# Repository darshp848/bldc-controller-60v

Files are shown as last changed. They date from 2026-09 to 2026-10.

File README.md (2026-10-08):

# bldc-controller-60v

A 48 V nominal / 60 V max BLDC motor controller that fits wherever a MAB Robotics MD80 v3.0
fits: same outline, mounting holes, Micro-Fit and AUX connectors, phase-wire holes and
encoder position, with the MD80's 20 A continuous / 80 A peak phase current.

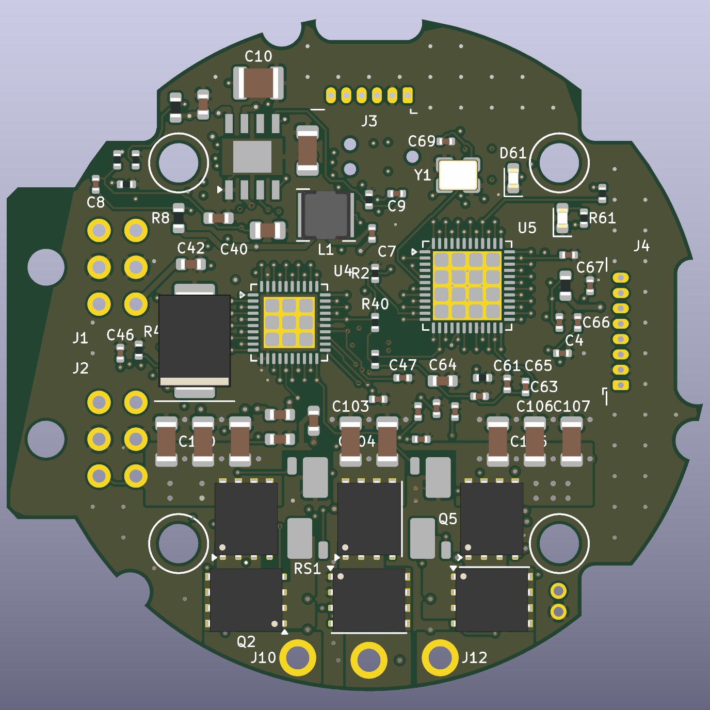
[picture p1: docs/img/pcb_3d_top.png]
top


## Status

| Item | State |
|---|---|
| Schematic (KiCad 10, 6 sheets, 137 symbols) | done, ERC 0 errors 0 warnings |
| PCB outline, holes, connectors vs MAB STEP | done, 36 holes match to 0.000 mm (`mech/fit_check.txt`) |
| PCB rev B (144 footprints, 6 layers) | routed; DRC: 0 unconnected, 1 error (MD80-inherent AUX1/screw overlap); two-shunt power stage, 5.0SMDJ60A TVS |
| Simulation | loop inductance, double pulse, bus surge, current loop: docs/simulation.md |
| Firmware | not started; pin map and bring-up values in docs/firmware.md |
| Bench validation | none; loss figures are estimates |

## Layout

```
hardware/            KiCad 10 project (open better-md80.kicad_pro)
  lib/               project symbol (DRV8353S) and MD80 footprints
  better-md80.kicad_dru   60 V clearance rules
docs/
  architecture.md    spec, what limits the MD80 to 48 V, part selection, power tree
  mechanical.md      MD80 fit data and what to verify before first power-up
  thermal_layout.md  loss budget, stack-up, layout rules
  firmware.md        pin map, clocks, DRV8353 settings, protection thresholds
  simulation.md      FastHenry / LTspice / MATLAB results and the changes they call for
  bom.csv            grouped BOM with MPNs
  schematic.pdf      all sheets
mech/                geometry extracted from MAB's MD80_V3.0_simplified.step
sim/                 simulation scripts (outputs in sim/out)
tools/               generators (design.py is the source of truth for the schematic)
```

## Regenerating

```bash
bash tools/build.sh
```

This rebuilds footprints, schematic, netlist, ERC/DRC reports, BOM, the schematic PDF and
the 3D renders. It leaves the routed PCB alone unless you run it with `REGEN_PCB=1`, which
regenerates the placement and throws the routing away (see tools/route.md to redo it).
Schematic changes reach the board through KiCad's Update PCB from Schematic as usual.

`tools/analyze_step.py` needs Python with CadQuery; everything else uses KiCad 10's
`kicad-cli` and bundled Python.

The KiCad files keep their original `better-md80` working name.

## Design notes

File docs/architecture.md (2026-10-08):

# Architecture and component selection

A drop-in replacement for the MAB Robotics MD80 v3.0 BLDC controller that runs from a
**48 V nominal bus (60 V maximum)** while keeping the MD80's board outline, mounting,
connectors, encoder position and its **20 A continuous / 80 A peak** phase current.

## Target specification

| Parameter | MD80 v3.0 | MD80 v3.0 60 V (MAB) | This design |
|---|---|---|---|
| Nominal input | 24-42 V | 48 V | 48 V (12S-13S Li-ion) |
| Operating range | 10-48 V | 12-60 V | 12-60 V |
| Transient withstand | not published | not published | 100 V parts, TVS clamps at 96.8 V @ 6.2 A |
| Continuous phase current (no cooling) | 20 A | 12 A | 20 A (see thermal notes) |
| Peak phase current (2 s) | 80 A | 40 A | 80 A |
| Max input current (connector) | 10 A RMS | 10 A RMS | 10 A RMS (same connector) |
| Outline / holes / connectors | 55 mm, 7 holes | same | identical, checked to 0.000 mm against MAB's STEP |
| Encoder | 14-bit on-axis | same | AS5047P, 14-bit, same TSSOP-14 height |
| Bus | CAN-FD 1/2/5/8 Mbit/s | same | CAN-FD up to 8 Mbit/s, switchable 120 Ohm termination |
| Aux ports | AUX1 SPI, AUX2 RS-422 + 2 GPIO, 5 V 150 mA | same | same pinout and connectors |

Sources: MAB documentation pages for [MD80](https://mabrobotics.github.io/MD80-x-CANdle-Documentation/MD/MD80.html)
and [MD80 60V](https://mabrobotics.github.io/MD80-x-CANdle-Documentation/MD/MD80HV.html), and MAB's
`MD80_V3.0_simplified.step` from their public 3D-model folder.

MAB's own 60 V variant already exists, but it halves the current rating. Keeping 80 A peak
at 60 V in the same 55 mm board is the actual engineering goal of this design.

## What limits the original to 48 V

MAB does not publish MD80 schematics, so this list is inferred from the published ratings,
photos and the STEP model rather than read from a schematic:

1. **Gate driver / pre-driver supply.** 48 V max with 24-42 V nominal matches the 60-65 V class
   of integrated three-phase drivers (e.g. the DRV832x family, 60 V abs max). Regen pumping
   the bus above ~50 V is what that margin protects.
2. **DC-link capacitors.** The MD80 uses a row of 1206 MLCCs top and bottom. At 42 V these are
   50 V parts; they are the cheapest place a 48 V limit comes from.
3. **Auxiliary buck regulator** feeding 5 V / 3.3 V, typically a 60 V-class part.
4. **MOSFETs.** The 60 V MAB variant keeps the footprint but drops to 40 A peak, which is the
   signature of moving to 100 V MOSFETs with higher R_DS(on) in the same package.

## What this design changes

| Function | Part used here | Rating | Why |
|---|---|---|---|
| Gate driver + CSA | TI **DRV8353SRTAR** (WQFN-40 6x6) | VDRAIN 100 V (102 V abs), VM 9-75 V | 100 V class, SPI-programmable IDRIVE, 3 low-side CSAs (gain 5/10/20/40), VDS and VGS monitoring |
| MOSFETs (x6) | Infineon **ISC022N10NM6ATMA1** (SuperSO8 5x6) | 100 V, 2.24 mOhm max @ 10 V | Lowest R_DS(on) 100 V part in the MD80's 5x6 footprint; this is what keeps 80 A peak |
| Shunts (x2, phases A and C) | 0.5 mOhm 2512 Kelvin (Vishay WSK2512), top side between the FETs | 3 W class | 10 mV/A; with CSA gain 20 gives +/-140 A range, 80 mA/LSB at 12 bit. Two-shunt sensing keeps the commutation loop at about 3 nH (docs/simulation.md) |
| DC-link | 24x **TDK C3216X7S2A225K160AB** 2.2 uF 100 V X7S 1206 | 100 V | Same 1206 rows as MD80 (12 top + 12 bottom), 53 uF nominal, ~20 uF at 48 V bias |
| Input TVS | Littelfuse **5.0SMDJ60A** (SMC) | VRWM 60 V, VC 96.8 V at 51.6 A | Holds a 60 V hot-plug through a 2 m cable below 100 V (the SMBJ60A reached 106 V in simulation) |
| 60 V -> 12 V | TI **LM5164DDAR** | 6-100 V in, 1 A | Feeds gate drive (DRV8353 VM) and the 5 V buck |
| 12 V -> 5 V | TI **TPS62163DSGR** | 3-17 V in, 1 A, fixed 5 V | CAN transceiver, AUX 5 V (150 mA), LDO input |
| 5 V -> 3.3 V | TI **TLV75533PDBVR** | 500 mA LDO | MCU, encoder, RS-422; ferrite-filtered +3V3A for analog/VREF |
| MCU | ST **STM32G474CEU6** (QFN-48) | 170 MHz M4F | TIM1 complementary PWM, 5 ADCs, 3 FDCAN, CORDIC/FMAC for FOC |
| CAN-FD | TI **TCAN1044AVDR** + Nexperia PESD2CAN | 8 Mbit/s, VIO 3.3 V, +/-58 V bus fault | Bus-fault rating matters now that the power pins carry 60 V next to CAN |
| Termination | IXYS **CPC1017N** PhotoMOS + 120 Ohm | 60 V | Software-switched termination like the MD80 |
| Encoder | ams **AS5047P-ATSM** (TSSOP-14) | 14 bit | Same package height as the MD80 encoder, so the 1 mm magnet gap is unchanged |
| RS-422 | **MAX3490EESA+** | 3.3 V full duplex | AUX2 for RLS AksIM-2 / Orbis |

### Why the gate driver runs from 12 V instead of the bus

DRV835x allows VM (gate-drive supply) to be separate from VDRAIN. Feeding VM from the 12 V
rail means the charge pump and low-side regulator dissipate `I_gate x 12 V` instead of
`I_gate x 60 V`. With six ~70 nC gates at 40 kHz plus ~9 mA quiescent, that is roughly
0.3 W instead of ~1.5 W inside a 6x6 QFN at 60 V. The cost is one 100 V buck (LM5164),
which is needed anyway for the logic rails.

## Power tree

```
VBUS 12-60 V --+-- 6x ISC022N10NM6 half-bridges -- motor
               +-- DRV8353 VDRAIN (HS drain sense + charge-pump reference)
               +-- 5.0SMDJ60A, 24x 2.2 uF/100 V, 100k/5.1k VBUS sense
               +-- LM5164 (400 kHz, UVLO ~10.8 V) --> +12V
                        +-- DRV8353 VM (gate drive)
                        +-- TPS62163 --> +5V --+-- TCAN1044 VCC, AUX1/AUX2 5 V out
                                               +-- TLV75533 --> +3V3 --+-- MCU, AS5047P, MAX3490, CAN VIO
                                                                        +-- ferrite --> +3V3A (VDDA, VREF+, DRV VREF, NTC bias)
```

## Schematic organisation

`hardware/better-md80.kicad_sch` is a hierarchical root with six sheets:

1. `power_input` - Micro-Fit connectors, TVS, DC-link rows, VBUS sense
2. `regulators` - LM5164, TPS62163, TLV75533, analog filter
3. `power_stage` - bridge, gate resistors (0 Ohm placeholders), Kelvin shunts, DNP RC snubbers, MOSFET NTC, phase pads
4. `gate_driver` - DRV8353S and its charge-pump/regulator capacitors, CSA output filters
5. `mcu` - STM32G474, 8 MHz HSE, Tag-Connect SWD, status LEDs
6. `comms_sensors` - CAN-FD, switchable termination, AS5047P, AUX1/AUX2, motor thermistor

Nets are connected with global labels on every pin, so a net has the same name on every
sheet. The schematic is generated from `tools/design.py`; edit that file and run
`bash tools/build.sh` rather than hand-editing the `.kicad_sch` files, or switch to editing
in KiCad and stop using the generator. Pick one; mixing them loses edits.

## BOM

`docs/bom.csv` is exported from the schematic (grouped, with MPN and notes, DNP marked).
Parts without an MPN are generic passives: use X7R/X7S, and at least 16 V for anything on
3.3 V/5 V nets, 25 V on the 12 V rail, 100 V on VBUS/phase nets (those already carry an MPN).
Items marked "verify" in the MPN column were chosen from memory of the product line and
have not been checked against a distributor listing yet:

- Vishay WSK2512 at 0.5 mOhm (if unavailable, a 0.5 mOhm 2512 Kelvin shunt from another series needs a footprint change)
- Bourns SRN4018-470M saturation current (needs >= 0.8 A; the 12 V rail draws ~0.25 A)
- Murata GRM188R72A473KA01D (47 nF 100 V 0603 charge-pump capacitor)
- Abracon ABM8-8.000MHZ-B2-T load capacitance vs the 10 pF load caps

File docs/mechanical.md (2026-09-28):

# Mechanical compatibility with MD80 v3.0

The board has to drop into the same actuators MAB sells with the MD80 (their CubeMars /
T-Motor based actuators and MA series). Every mechanical feature is taken from MAB's
`MD80_V3.0_simplified.step` (public 3D-model folder linked from the MD80 docs page).

## How the geometry was extracted

`tools/analyze_step.py` loads the STEP with CadQuery, picks the 1.6 mm PCB solid, and
dumps its top-face outline and every circular hole to `mech/md80_v3_mech.json`. From that:

- `tools/gen_pcb.py` copies the outline (lines and arcs) to Edge.Cuts unchanged.
- `tools/gen_fp.py` builds `MD80_V3_Mechanical` (holes + keep-outs) from the hole list.
- `tools/check_fit.py` compares every drilled hole on our board with every round hole in
  the STEP. Result (`mech/fit_check.txt`): **36 holes, worst position error 0.000 mm,
  all diameters equal.**

Coordinates below are STEP coordinates, origin on the rotor axis, +Y towards AUX1.

| Feature | Position (mm) | Size |
|---|---|---|
| Mounting holes (4) | (+/-15.5, +/-15.5) | 3.2 mm, M2.5 DIN912; 4.8 mm standoff keep-out both sides |
| Edge screw notches (3) | (26.56, -7.12), (-7.12, 26.57), (-19.45, -19.45) | R1.6 half-holes, 4.5 mm head keep-out |
| Micro-Fit pegs | (-26.3, +7.0), (-26.3, -7.0) | 3.0 mm (the lower one is a non-round cut-out in the STEP; modelled as 3.0 mm) |
| Micro-Fit J1 / J2 pins | x = -21.98 / -18.98, y = 4, 7, 10 and -4, -7, -10 | 1.07 mm drill, 3.0 mm pitch |
| AUX1 (PicoBlade 6) | y = 21.0, x = +3.15 ... -3.10 | 0.5 mm drill, 1.25 mm pitch, pin 1 at +x |
| AUX2 (PicoBlade 8) | x = 20.5, y = -2.60 ... +6.15 | 0.5 mm drill, pin 1 at -y |
| Phase wire holes | (-5.8, -24.8), (0, -25.0), (5.8, -24.8) | 1.9 mm drill |
| Motor thermistor pads | (15.43, -19.35), (15.43, -21.05) | 0.8 mm drill |
| Encoder IC | (0, 0), bottom side | TSSOP-14, 1.2 mm tall (MD80 part is also 1.2 mm) |

Height envelope measured from the STEP: components reach **4.0 mm above** the top copper
(excluding connectors) and **2.3 mm below** the bottom. The tallest top parts here are the
SMB TVS (2.3 mm), the 1210 capacitor (2.5 mm) and L1 (1.8 mm); the tallest bottom parts
are SOIC-8 (1.75 mm) and SOP-4 (2.1 mm). All fit inside the MD80 envelope.

## Things to verify before the first build

1. **Micro-Fit pin assignment.** MAB's diagram shows columns CAN / GND / VCC with CAN H on the
   row nearest the board, but the picture does not say which way round it is drawn. The
   board uses: edge row (x = -21.98) CAN H / GND / VBUS at y = +10 / +7 / +4, rear row
   CAN L / GND / VBUS. Check continuity against a genuine MD80 or a MAB cable before power-up;
   getting this wrong puts 60 V on CAN. The mapping is one line (`MICROFIT_PINS` in
   `tools/design.py`).
2. **AUX pin order.** Pin 1 = +5 V is assumed at the end shown on MAB's AUX photos
   (+x end for AUX1, -y end for AUX2). Same check with a MAB encoder cable.
3. **Screw notch next to AUX1.** The only remaining DRC error is J3's courtyard touching the
   screw-head keep-out of the notch at (-7.12, 26.57). The MD80 has the connector in the same
   place, so it fits in practice, but look at it with the real screw.
4. **3D models.** The Micro-Fit, phase-pad and mechanical footprints have no 3D model yet, so
   the KiCad 3D view does not show the connector bodies.

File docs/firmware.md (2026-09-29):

# Firmware notes

MAB's MD80 firmware is closed and built for MAB's hardware, so it will not run on this
board. The firmware has to be written (or ported from an open FOC stack such as the
moteus, ODrive or SimpleFOC code bases) against the pin map below. To keep working with
MAB's CANdle and actuators, it also has to speak MAB's CAN-FD frame and register
protocol, which is documented on the MAB site.

## Pin map (STM32G474CEU6, QFN-48)

| Function | Pin | Peripheral |
|---|---|---|
| INHA / INHB / INHC | PA8 / PA9 / PA10 | TIM1_CH1 / CH2 / CH3 (AF6) |
| INLA / INLB / INLC | PB13 / PB14 / PB15 | TIM1_CH1N / CH2N / CH3N (AF6) |
| SOA / SOC | PA0 / PA2 | ADC12_IN1 / ADC1_IN3 (SOB on PA1 reads the unused CSA, ignore it) |
| VBUS_SENSE | PA3 | ADC1_IN4 (100k / 5.1k, 20.6:1) |
| TEMP_FET / TEMP_MOTOR | PB0 / PB1 | ADC1_IN15 / ADC1_IN12 (10k pull-up to 3V3A) |
| DRV8353 SPI | PA5 SCK, PA6 MISO, PA7 MOSI, PA4 nCS | SPI1 (AF5), mode 1, <= 10 MHz |
| DRV_EN / DRV_nFAULT | PC6 / PC10 | GPIO out (100k pull-down) / EXTI in |
| Encoder + AUX1 SPI | PB3 SCK, PB4 MISO, PB5 MOSI | SPI3 (AF6), mode 1 |
| Encoder nCS / AUX1 nCS | PA15 / PB9 | GPIO |
| RS-422 TX / RX | PB10 / PB11 | USART3 (AF7), or TIM for BiSS/SSI clocking |
| AUX GPIO A / B | PB6 / PB7 | GPIO / TIM4_CH1-2 (brake PWM on GPIO B as MD80) |
| CAN RX / TX | PA11 / PA12 | FDCAN1 (AF9) |
| CAN termination | PB12 | GPIO, high = 120 Ohm on |
| LED green / red | PC13 / PC11 | GPIO |
| HSE 8 MHz | PF0 / PF1 | |
| SWD | PA13 / PA14, NRST | Tag-Connect TC2030-NL (SWO not connected; PB3 is SPI3) |
| BOOT0 | PB8 | 10k pull-down; set nSWBOOT0 in option bytes |

Confirm the ADC channel numbers in CubeMX before writing drivers; they were taken from the
G474 alternate-function table, not generated.

## Clocks

HSE 8 MHz -> PLL (M = 2, N = 80) -> VCO 320 MHz; R = 2 gives SYSCLK 160 MHz, Q = 4 gives
FDCAN 80 MHz. 80 MHz divides evenly into 1, 2, 5 and 8 Mbit/s (10 time quanta at 8 Mbit/s),
which 170 MHz would not.

## PWM, sensing, control

- TIM1 centre-aligned, ARR = 2000 at 160 MHz -> 40 kHz. DRV8353 in 6x PWM mode; MCU dead time
  ~150 ns on top of the driver's handshake dead time.
- **Two-shunt sensing (layout rev B):** shunts on phases A and C only; phase B's low side goes
  straight to GND, so ib = -(ia + ic). Sample SOA and SOC at the counter underflow (all
  low-side FETs on), ADC1+ADC2 dual simultaneous, triggered from TIM1 TRGO2. Both measured
  phases need their low side on for about 2 us, so limit the A and C duty to about 92 %; phase B can
  go to 100 %. With 0.5 mOhm shunts and CSA gain 20: 10 mV/A, +/-140 A range,
  ~80 mA per LSB.
- Loop rates to match the MD80: current/torque and impedance 40 kHz, velocity 5 kHz,
  position 1 kHz. CORDIC for sin/cos, FMAC optional.

## DRV8353S SPI configuration (starting values)

| Register field | Value | Reason |
|---|---|---|
| PWM_MODE | 6x | independent HS/LS from TIM1 |
| IDRIVEP_HS/LS | 300 mA | ~50 ns Miller plateau on ISC022N10NM6, tune for ringing |
| IDRIVEN_HS/LS | 600 mA | |
| TDRIVE | 1000 ns | |
| VDS_LVL | 0.45 V | trips at ~130 A hot / ~200 A cold R_DS(on) |
| OCP_MODE | latched fault | report over CAN, clear with ENABLE pulse |
| CSA_GAIN | 20 V/V | see above |
| VREF_DIV | on | output centred at VREF/2 = 1.65 V |
| DEAD_TIME | 100 ns | plus MCU dead time |

## Protection thresholds (60 V design)

| Condition | Threshold | Action |
|---|---|---|
| Undervoltage | VBUS < 10.5 V | disable bridge (LM5164 UVLO is ~10.8 V rising) |
| Regen soft limit | VBUS > 56 V | ramp regenerative (negative-power) current limit to zero |
| Overvoltage fault | VBUS > 63 V | disable bridge, flag fault |
| Hardware | TVS conducts from 66.7 V | last resort only; it cannot absorb braking energy |
| MOSFET temperature | 100 C, 20 C hysteresis | same as MD80 |
| Motor temperature | user limit <= 140 C | same as MD80 |
| Phase overcurrent | software limit from config, DRV VDS OCP as backstop | |

There is no brake resistor on the MD80 or on this board. On a battery bus the battery takes
the regen current; on a lab supply that cannot sink current the bus will pump up during hard
deceleration, which is what the 56 V / 63 V thresholds are for.

## Encoder

AS5047P over SPI3 at up to 10 MHz, 14-bit angle (register 0x3FFF, even parity). AUX1 shares
SCK/MOSI/MISO through 33 Ohm series resistors with its own chip select, so external SPI
encoders (MAB ME-am, CubeMars CM) keep working. AUX2 RS-422 serves the RLS AksIM-2 / Orbis.

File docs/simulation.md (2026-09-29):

# Simulation report

## Layout rev B (current board)

Changes driven by the rev A results below: D1 is now a 5.0SMDJ60A (SMC), the power stage
uses two top-side shunts (phases A and C) standing between the high-side FETs, and phase
B's low side returns straight into the GND plane.

| Check | Rev A | Rev B |
|---|---|---|
| Commutation loop, phase A/C (FastHenry, `loop_inductance.py --rev-b`) | 5.0 nH | **2.96 nH** |
| Commutation loop, phase B | 5.0 nH | **2.70 nH** |
| Hot-plug 60 V through 2 m cable | 106 V (SMBJ60A) | **96 V (5.0SMDJ60A)** |
| Double pulse 60 V / 80 A, diode-recovery peak (IDRIVE 300 mA) | 83 V | 86 V |
| Double pulse 60 V / 20 A | 76 V | 71 V |
| Double pulse 60 V / 80 A with snubbers fitted | 60 V | 66 V |

The shorter loop raises the ringing frequency (about 70 -> 95 MHz) but does not lower the 80 A
peak, which is set by the body-diode recovery of the ISC022N10NM6 at this gate drive. The
100 V FETs keep about 14 V of margin at the worst case; keep IDRIVEP at 300 mA and fit the
snubbers on the first boards.

Remaining layout weaknesses in rev B: crystal traces 18 / 26 mm (the MCU surroundings are full
of fan-out vias), gate traces 24-31 mm, and 52 reference designators hidden for lack of room.

# Rev A results (first layout pass)

Tools on the design laptop: FastHenry2 (loop inductance), LTspice 26 (switching and bus
transients), MATLAB R2026a + Control System Toolbox (current loop). Every run is a script
in `sim/`; plots and numbers land in `sim/out/`.

| Script | What it answers |
|---|---|
| `sim/loop_inductance.py` | Commutation-loop inductance of a half-bridge from the routed copper |
| `sim/double_pulse.py` | Switch-node overshoot and ringing at 48/60 V, 20/80 A |
| `sim/bus_surge.py` | Hot-plug overshoot and regenerative pump-up of the DC bus |
| `sim/foc_current_loop.m` | Current-loop margins, bandwidth and noise with the real sensing chain |

## 1. Commutation loop inductance (FastHenry2)

Phase B loop, following the routed copper: DC-link capacitor, VBUS pour, high-side FET,
phase pour, low-side FET, low-side pour and its 5 vias, Kelvin shunt on B.Cu, 3 ground
vias, meshed In1 GND plane back to the capacitor. MOSFET packages are modelled as 0.6 mm
straps.

| Case | L at 10-100 MHz |
|---|---|
| As routed (5 LS vias, 3 shunt GND vias) | **5.0 nH** |
| 10 LS vias, 8 shunt GND vias | 4.9 nH |
| High-frequency loop through the local 100 nF (C26) | 5.1 nH |

More vias barely help: the loop area is set by the MD80 geometry (DC-link row at
y = -7 mm, low-side FETs and shunts at y = -20 mm, shunts on the bottom side). 5 nH is
workable at 60 V with the drive strength below, but it is the number to attack in a
layout revision: moving the shunts to the top side next to the low-side sources, or
adding 100 nF 100 V 0402s directly across each half-bridge, would roughly halve it.

## 2. Double-pulse test (LTspice)

ISC022N10NM6 VDMOS model fitted to the Infineon datasheet Rev 2.1 (Ciss 5400 pF,
Coss 1200 pF and Crss 19 pF at 50 V, Qg 73 nC, Qgd 11.9 nC, Qoss 135 nC, Qrr 70 nC,
RG 1.4 Ohm), 5.0 nH loop, 15 nH routed gate trace, DRV8353 IDRIVE as set in firmware.

| Case | Low-side turn-off peak | High-side peak at low-side turn-on (diode recovery) |
|---|---|---|
| 60 V, 80 A, IDRIVE 300/600 mA | 64.8 V | **83.2 V** |
| 60 V, 20 A | 62.5 V | 75.6 V |
| 48 V, 80 A | 52.8 V | 77.1 V |
| 60 V, 80 A, IDRIVE 700/1400 mA | 64.9 V | **95.1 V** |
| 60 V, 80 A, RC snubber 2.2 Ohm + 2.2 nF fitted | 64.8 V | 60.3 V |

The critical event is not turn-off but the body-diode recovery of the opposite FET.
With IDRIVE capped at 300 mA source the worst case keeps 17 V of margin on the 100 V
parts; faster drive leaves under 5 V. Recommendation: keep IDRIVEP at or below 300 mA
in firmware, and fit the DNP snubbers (R30-R32, C23/C27/C31) on the first boards until
the ringing is measured. Ringing is 60-80 MHz; snubber loss at 40 kHz is about
0.5 x 2.2 nF x 60^2 x 2 x 40 kHz = 0.32 W per phase in the 0805 resistor, which is at its limit, so
use a 1206 or 2x 0805 if the snubbers stay.

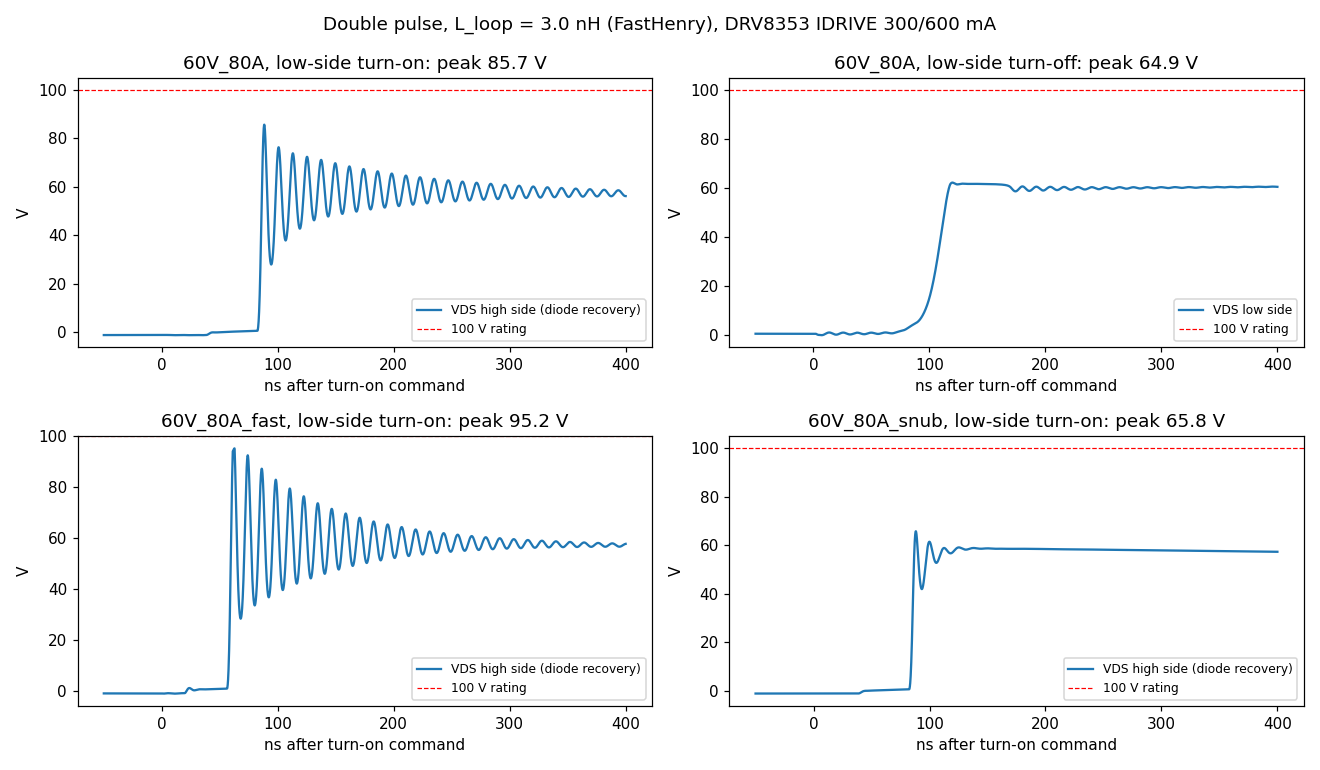
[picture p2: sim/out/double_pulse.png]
double pulse


## 3. DC-bus transients (LTspice)

Bus: 24x 2.2 uF 100 V X7S, about 20 uF left at 60 V bias.

| Case | Peak bus voltage |
|---|---|
| Hot-plug onto 60 V, 0.5 m cable, SMBJ60A | 97.9 V |
| Hot-plug onto 60 V, 2 m cable, SMBJ60A | **106.2 V (exceeds 100 V parts)** |
| same, no TVS | 108.2 V |
| same, SMCJ60A | 103.7 V |
| same, **5.0SMDJ60A** (SMC package) | **96.4 V** |
| same, SMBJ60A + 100 uF electrolytic at the supply | 72.3 V |
| Regen 5 A into a supply that cannot sink, board caps only | 88 V (reaches 63 V in 12 us) |
| Regen 20 A, board caps only | 147 V (TVS overwhelmed) |
| Regen 20 A, + 470 uF external | 71 V |
| Regen 20 A, board caps, 5.0SMDJ60A | 81 V |

Findings that change the design or its operating rules:

1. **D1 should be a Littelfuse 5.0SMDJ60A** (5 kW, SMC/DO-214AB, 2.3 mm tall, fits the
   MD80 height envelope). The SMBJ60A cannot hold a 60 V hot-plug through a 2 m cable
   below 100 V. This needs the D1 footprint changed from SMB to SMC in the next layout
   pass. Until then, do not hot-plug above 48 V (peak scales with the bus: about 85 V at 48 V).
2. **At 60 V the bus must be able to absorb regenerative energy.** 20 uF of ceramics
   charge 3 V in 12 us at only 5 A of braking current, far faster than a 40 kHz control
   loop can react. Run 60 V systems from a battery, or put at least 470 uF on the bus
   near the actuators (the MAB PDS or an equivalent power board), or add a brake chopper.
   Firmware regen limiting (docs/firmware.md) still matters, but it is not sufficient alone.

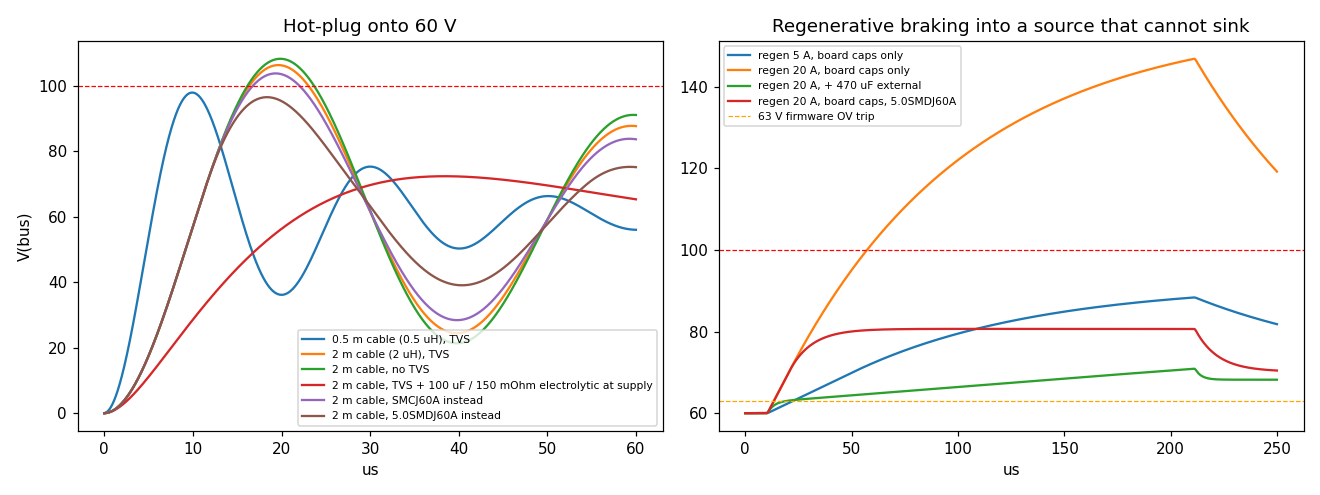
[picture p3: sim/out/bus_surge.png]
bus surge


## 4. Current loop (MATLAB)

Discrete PI at 40 kHz, 1.5-sample delay, 0.5 mOhm shunt, CSA gain 20, 12-bit ADC
(80.6 mA/LSB, +/-165 A), 50 mA rms analog noise, SVPWM voltage limit at 48 V. Motor
R = 0.20 Ohm, L = 90 uH (assumed 8108-class actuator motor; replace with measured values).

| Target bandwidth | Phase margin | Gain margin | Closed-loop -3 dB | Noise at 20 A |
|---|---|---|---|---|
| 1.0 kHz | 76.5 deg | 16.5 dB | 1.36 kHz | 7 mA rms |
| 2.5 kHz (MD80 maximum) | 56.3 deg | 8.5 dB | 5.97 kHz | 52 mA rms |

The sensing chain supports the MD80's full 2.5 kHz torque bandwidth with healthy margin.
Three-shunt sampling at the PWM valley needs about 1 us of CSA settling, which caps the
modulation at 92 % duty; above that, reconstruct the third phase from the other two.

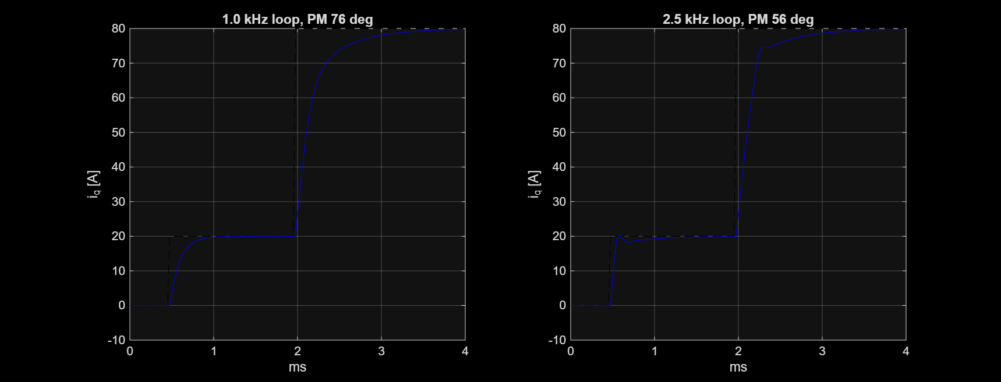
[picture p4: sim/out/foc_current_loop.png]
current loop


## 5. Signal integrity (by calculation, not field-solved)

| Net | Routed length | Assessment |
|---|---|---|
| CANH / CANL | 54 / 37 mm | CAN-FD at 8 Mbit/s has ~15-25 ns edges; the on-board stub is far below the ~1.5 m critical length. Fine. |
| SPI3 (encoder + AUX1) | 30-34 mm, 2-3 vias | Fine at the AS5047P's 10 MHz. |
| **HSE crystal** | **16 / 33 mm, 2-3 vias** | **Too long.** The packer placed Y1 away from the MCU. Move Y1 and C68/C69 within 3 mm of PF0/PF1 in the next pass; otherwise expect oscillator start-up margin problems. |
| Gate drive GHx/GLx | 21-27 mm, 2 vias | Longer than ideal (target under 15 mm); included in the double-pulse model as 15 nH. |

## 6. Copper loss in the power path (by calculation)

Sheet resistance: 2 oz outer 0.25 mOhm/sq, 1 oz inner 0.49 mOhm/sq.

| Path | Estimate | Loss at 20 A RMS | at 80 A peak |
|---|---|---|---|
| Phase pour FET to wire hole (F.Cu + In4), per phase | 0.25 mOhm | 0.10 W | 1.6 W (2 s) |
| VBUS from Micro-Fit to the bridge (In4 plane + pours) | 0.7 mOhm | 0.07 W at 10 A input | |

Negligible next to the ~9 W semiconductor loss in docs/thermal_layout.md.

## Changes these results call for

| # | Change | Why |
|---|---|---|
| 1 | D1 SMBJ60A -> 5.0SMDJ60A (SMC footprint) | Hot-plug at 60 V exceeds 100 V otherwise |
| 2 | Firmware IDRIVEP <= 300 mA | Diode-recovery overshoot 95 V at 700 mA |
| 3 | Fit snubbers on first boards, 1206 resistor | Ringing damping until measured |
| 4 | Move Y1 next to the MCU | 16-33 mm crystal traces |
| 5 | Operating rule: 60 V only with a battery or >= 470 uF bus capacitance | Regen pump-up |
| 6 | Next layout: shunts to top side / extra local HF caps | Cut the 5 nH loop roughly in half |

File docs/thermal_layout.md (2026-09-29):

# Thermal and layout notes

## Loss budget (estimate, not measured)

Assumptions: 48 V bus, 20 A RMS phase current, 40 kHz centre-aligned PWM (the MD80's
torque-loop rate), MOSFET R_DS(on) 2.24 mOhm max at 25 C, taken as 3.4 mOhm hot (x1.5),
~30 ns rise and fall with DRV8353 IDRIVE at 300 mA source / 600 mA sink.

| Loss | Formula | Per phase | Total |
|---|---|---|---|
| Conduction | I_rms^2 x R_hot | 1.36 W | 4.1 W |
| Switching | 0.5 x V x I_avg x (tr + tf) x f, I_avg = 0.9 x I_rms | 1.0 W | 3.1 W |
| Output charge + dead-time diode | Qoss x V x f + Vf x I x 2 t_dead x f | ~0.35 W | ~1 W |
| Shunts | I^2 x R x duty (LS share ~0.5) | 0.1 W | 0.3 W |
| Gate drive + DRV quiescent (12 V) | | | 0.3 W |
| LM5164 + TPS62163 | ~85 % at ~2.6 W out | | 0.5 W |
| **Total** | | | **~9 W** |

At 60 V the switching term rises to ~3.9 W (total ~10 W). The MD80 at 42 V and 20 A lands
around 8 W with the same method, so 48 V costs roughly 10-15 % more heat for the same
current. Options if bench testing shows the FETs run hot:

- drop PWM to 20-25 kHz above 48 V (halves switching loss; still above audible range at 25 kHz)
- raise IDRIVE after checking ringing (faster edges, less switching loss)
- use MAB's thermal bridge / heat-sink pad under the power stage as on the MD80

The firmware MOSFET limit stays at the MD80's 100 C shutdown with 20 C hysteresis (NTC TH1
sits under the phase B FETs on the bottom side, as on the MD80).

At 80 A for 2 s: conduction ~22 W per phase pair is carried by thermal mass. The
ISC022N10NM6 pulse rating (920 A) and SuperSO8 junction-to-case (~0.5 K/W class) are far
from the limit; the limiting factor is copper temperature rise in the phase and VBUS pours,
which is why the power stage copper is poured on the outer layers and In4.

## Stack-up

6 layers, 1.6 mm, 2 oz outer / 1 oz inner (2 oz on In4 preferred for 80 A peak). The board
went from 4 to 6 layers during routing: on 4 layers the 18 gate-drive and Kelvin nets from the
DRV8353 could not cross the DC-link rows with In1 and In2 reserved for GND and VBUS.

| Layer | Use |
|---|---|
| F.Cu | MOSFETs, DRV8353, MCU, regulators; VBUS, phase and low-side pours; GND fill |
| In1.Cu | Solid GND reference plane (no signal routing) |
| In2.Cu | Signals; GND fill |
| In3.Cu | Signals; GND fill |
| In4.Cu | VBUS plane from the Micro-Fits to the bridge, phase copper under the FETs; GND fill |
| B.Cu | Shunts, DC-link second row, encoder, CAN, RS-422; low-side pours; GND fill |

Design rules: default 0.15 mm track/space, 0.45/0.2 mm vias (0.1 mm minimum where the
autorouter necked down at pads); HV_60V class 0.4 mm tracks, 0.6/0.3 mm vias, 0.2 mm clearance.

## Layout rules

1. **Commutation loop first.** Each half-bridge's HS drain, LS source/shunt and the DC-link
   capacitors form the smallest loop the MD80 outline allows: HS FETs directly under the top
   capacitor row, shunts on the top side next to the low-side sources, shunt ground ends
   via'd straight into In1 beside the DC-link row.
2. **Kelvin sensing.** SPA/SNA and SPC/SNC run from the inner shunt pads (pads 2 and 3 of the
   WSK2512 footprint) to the DRV8353. CSA B's inputs are tied to GND (two-shunt sensing).
3. **Gate loops.** GHx and SHx run as a pair, GLx paired with its LS source; keep under
   ~15 mm. The 0 Ohm gate resistors (R20-R25) are there to add 2-5 Ohm if ringing needs it.
4. **Snubbers.** R30-R32 / C23, C27, C31 are DNP; fit only if the phase-node ringing on the
   first board exceeds ~15 V overshoot at 60 V.
5. **60 V clearance: conformal coating is required.** Net class `HV_60V` (VBUS, phase nets,
   high-side gate nets, charge pump, LM5164 switch node, snubbers) is routed at 0.2 mm, with
   0.15 mm allowed only in the DRV8353/LM5164 fan-out areas and at MOSFET pins
   (`hardware/better-md80.kicad_dru`). That meets IPC-2221B B4 (external, coated: 0.13 mm for
   51-100 V) but not B2 (uncoated: 0.6 mm), so coat the power stage and gate-drive area.
6. **CAN next to 60 V.** The Micro-Fit puts CAN H one pin from VBUS. Keep CANH/CANL routed
   as a 120 Ohm differential pair on the side away from VBUS, and keep the TCAN1044 and
   PESD2CAN close to the connector. The TCAN1044A survives +/-58 V bus faults, not 60 V; the
   PESD2CAN clamps the rest.
7. **Encoder.** Keep a 3 mm radius around U7 free of vias carrying switching current and
   keep phase and VBUS pours out of the region directly under the magnet.
8. **Buck layout.** LM5164 input caps (C5, C6) within 2 mm of VIN/GND; the SW node
   (SW12) small; the ripple-injection network (R8, C8, C9) next to FB.
9. **Screw keep-outs.** Silkscreen rings mark the 4.8 mm standoff / screw-head area at every
   mounting hole. No copper other than GND inside them (the MD80 docs warn about screw
   heads shorting to planes).

## Layout status

Placement is generated by `tools/gen_pcb.py` (mechanical parts at MD80 coordinates, packer for
the rest, 2.2 mm fan-out rings around the DRV8353 and MCU). Routing flow (`tools/route.md`):

1. `route_pcb.py pours`: local power-stage pours, power vias, hand fan-out of the two QFNs, DSN export
2. Freerouting 2.4.1 (JRE 25) on 5 signal layers, In1 locked as a power plane
3. `route_pcb.py import`, then `hand_route.py` (grid A* router) for what the autorouter left
4. `route_pcb.py final`: board-wide GND pours, VBUS plane, stitching vias, silkscreen fixer
5. `cleanup.py` for hole-to-hole and silkscreen DRC warnings

Rev B power stage: high-side FETs at y = -13.5 mm, low-side FETs at y = -20.1 mm, the phase A
and C Kelvin shunts standing on the top side in the gaps between the high-side FETs (their
ground ends via straight into In1 next to the DC-link row), phase B's low side straight to GND.
The 5.0SMDJ60A sits next to the Micro-Fits. Commutation loop about 3 nH (docs/simulation.md).

Known weaknesses (details in docs/simulation.md): 8 MHz crystal traces 18 / 26 mm, gate traces
24-31 mm, and 52 reference designators hidden for lack of room (they stay on the fab layer).

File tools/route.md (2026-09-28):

# Re-running the layout flow

Only needed if the placement is regenerated (`REGEN_PCB=1 bash tools/build.sh`), which
discards all routing. Normal edits should be made in KiCad directly.

Tools: KiCad 10 (per-user install), Freerouting 2.4.1 (`C:/Users/darsh/tools/freerouting-2.4.1.jar`)
and the JRE 25 next to it. Commands assume Git Bash in the repo root.

```bash
K=/c/Users/darsh/AppData/Local/Programs/KiCad/10.0/bin
cd hardware
# 1. local power pours, power vias, QFN fan-out, Specctra export -> route/board.dsn
"$K/python.exe" ../tools/route_pcb.py pours
cp better-md80.kicad_pcb route/pre.kicad_pcb
# 2. keep the In1 GND plane free of signals
sed -i '/(layer In1.Cu/{n;s/(type signal)/(type power)/}' route/board.dsn
# 3. autoroute
/c/Users/darsh/tools/jdk-25.0.4.1+1-jre/bin/java.exe -jar /c/Users/darsh/tools/freerouting-2.4.1.jar \
    -de route/board.dsn -do route/board.ses -mp 8 -mt 16 --gui.enabled=false
cd ..
# 4. import, hand-route leftovers, board-wide pours + stitching, silkscreen, DRC
bash tools/route_finish.sh route
```

Lessons that shaped this flow:

- KiCad's Specctra export turns DRC rule areas into keep-outs, so rule areas are added
  after routing (`route_pcb.py final`).
- Board-wide pours exported as planes block the router on their layer; only local
  power-stage pours go in before routing.
- Freerouting routes on In1 unless the DSN marks it `(type power)`.
- In KiCad 10's Python, `board.GetTracks()` / `board.Zones()` must be read before any
  `board.Remove()`; calling them afterwards crashes or returns an unusable object.

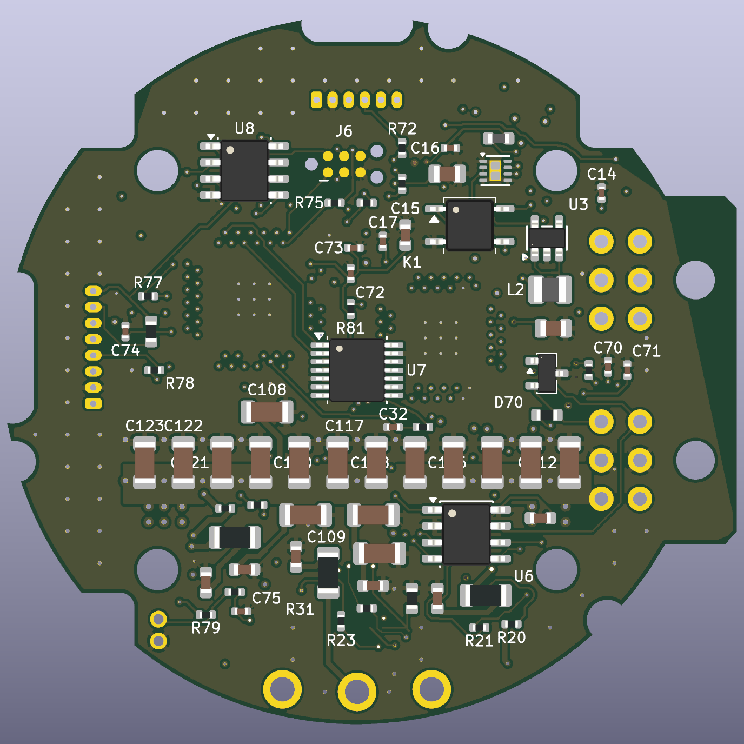
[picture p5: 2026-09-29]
docs/img/pcb_3d_bottom.png

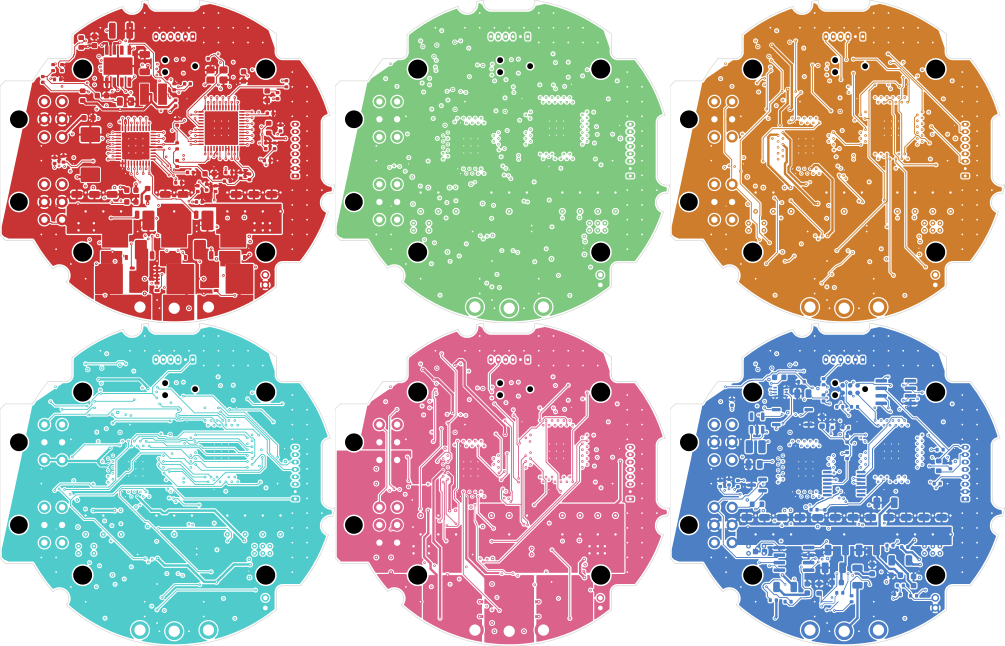
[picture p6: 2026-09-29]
docs/img/copper_layers.png

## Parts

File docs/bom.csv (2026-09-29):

Refs | Value | Footprint | MPN | Qty | DNP | Note
C4 | 10n | Capacitor_SMD:C_0402_1005Metric |  | 1
C5,C100-C123 | 2.2u 100V | Capacitor_SMD:C_1206_3216Metric | TDK C3216X7S2A225K160AB | 25 |  | DC-link row, 12 top + 12 bottom as on MD80
C6,C22,C26,C30,C42 | 100n 100V | Capacitor_SMD:C_0603_1608Metric | Murata GRM188R72A104KA35D | 5 |  | Place across HS drain / LS source,VDRAIN local
C7 | 2.2n | Capacitor_SMD:C_0402_1005Metric |  | 1
C8 | 3.3n | Capacitor_SMD:C_0402_1005Metric |  | 1
C9 | 56p | Capacitor_SMD:C_0402_1005Metric |  | 1
C10 | 22u 25V | Capacitor_SMD:C_1210_3225Metric | Taiyo Yuden TMK325B7226KMHT | 1
C11,C44,C45 | 1u 25V | Capacitor_SMD:C_0603_1608Metric |  | 3
C12,C40 | 10u 25V | Capacitor_SMD:C_0805_2012Metric |  | 2
C13 | 22u 10V | Capacitor_SMD:C_0805_2012Metric |  | 1
C14,C16,C46,C65,C73 | 1u | Capacitor_SMD:C_0402_1005Metric |  | 5 |  | VDDA
C15 | 2.2u | Capacitor_SMD:C_0603_1608Metric |  | 1
C17,C32,C47,C60-C63,C66,C67,C70-C72,C74,C75 | 100n | Capacitor_SMD:C_0402_1005Metric |  | 14 |  | VBAT,VREF,VREF+
C23,C27,C31 | 2.2n 100V | Capacitor_SMD:C_0603_1608Metric |  | 3 | DNP
C41 | 100n 25V | Capacitor_SMD:C_0402_1005Metric |  | 1
C43 | 47n 100V | Capacitor_SMD:C_0603_1608Metric | Murata GRM188R72A473KA01D (verify) | 1
C48-C50 | 470p | Capacitor_SMD:C_0402_1005Metric |  | 3 |  | CSA output filter, at MCU pin
C64 | 4.7u | Capacitor_SMD:C_0603_1608Metric |  | 1
C68,C69 | 10p | Capacitor_SMD:C_0402_1005Metric |  | 2
D1 | 5.0SMDJ60A | Diode_SMD:D_SMC | Littelfuse 5.0SMDJ60A | 1 |  | 5 kW TVS, VRWM 60 V, VC 96.8 V @ 51.6 A; sized by sim/bus_surge.py
D60 | Green | LED_SMD:LED_0603_1608Metric | Kingbright APTD1608LZGCK | 1
D61 | Red | LED_SMD:LED_0603_1608Metric | Kingbright APTD1608LSURCK | 1
D70 | PESD2CAN | Package_TO_SOT_SMD:SOT-23 | Nexperia PESD2CAN,215 | 1
FB1 | BLM18PG221 | Inductor_SMD:L_0603_1608Metric | Murata BLM18PG221SN1D | 1
J1,J2 | Micro-Fit 2x3 | better_md80:MD80_MicroFit_2x03_RA | Molex 43045-0600 (R/A, 2x3) | 2 |  | Power + CAN daisy-chain, MD80 position; pinout see docs/mechanical.md
J3 | AUX1 SPI enc | Connector_Molex:Molex_PicoBlade_53048-0610_1x06_P1.25mm_Horizontal | Molex 53048-0650 | 1 |  | MD80 AUX1 pinout
J4 | AUX2 RS422 | Connector_Molex:Molex_PicoBlade_53048-0810_1x08_P1.25mm_Horizontal | Molex 53048-0850 | 1 |  | MD80 AUX2 pinout
J5 | Motor NTC | better_md80:MD80_NTC_Pads |  | 1 |  | Solder pads for MAB motor thermistor
J6 | TC2030-NL | Connector:Tag-Connect_TC2030-IDC-NL_2x03_P1.27mm_Vertical |  | 1
J10 | Phase A | better_md80:MD80_Phase_Pad |  | 1 |  | Motor lead solder pad
J11 | Phase B | better_md80:MD80_Phase_Pad |  | 1 |  | Motor lead solder pad
J12 | Phase C | better_md80:MD80_Phase_Pad |  | 1 |  | Motor lead solder pad
K1 | CPC1017N | Package_SO:SOP-4_3.8x4.1mm_P2.54mm | IXYS CPC1017NTR | 1 |  | Software termination switch (60 V PhotoMOS)
L1 | 47u | Inductor_SMD:L_Bourns-SRN4018 | Bourns SRN4018-470M (verify Isat) | 1
L2 | 2.2u | Inductor_SMD:L_1008_2520Metric | Murata DFE252012F-2R2M | 1
MECH1 | MD80 v3 holes | better_md80:MD80_V3_Mechanical |  | 1 |  | 4x M2.5 holes + Micro-Fit peg holes at MD80 v3.0 coordinates
Q1-Q6 | ISC022N10NM6 | Package_TO_SOT_SMD:TDSON-8-1 | Infineon ISC022N10NM6ATMA1 | 6 |  | 100 V, 2.2 mOhm, SuperSO8
R1,R3 | 100k | Resistor_SMD:R_0603_1608Metric |  | 2 |  | UVLO on ~10.8 V,VBUS divider 20.6:1, 68 V -> 3.30 V
R2 | 5.1k | Resistor_SMD:R_0402_1005Metric |  | 1
R4 | 16.2k | Resistor_SMD:R_0402_1005Metric |  | 1
R5 | 75k | Resistor_SMD:R_0402_1005Metric |  | 1 |  | fsw = 12*2500/75k = 400 kHz
R6 | 453k | Resistor_SMD:R_0402_1005Metric |  | 1 |  | Vout = 1.2*(1+453/49.9) = 12.1 V
R7 | 49.9k | Resistor_SMD:R_0402_1005Metric |  | 1
R8 | 453k | Resistor_SMD:R_0603_1608Metric |  | 1 |  | Ripple injection (Type 3), per LM5164 EVM
R20-R25,R81 | 0 | Resistor_SMD:R_0402_1005Metric |  | 7 |  | 3.3 V mode: VDD3V3 tied to VDD,Gate resistor, tune for ringing
R30-R32 | 2.2 | Resistor_SMD:R_1206_3216Metric |  | 3 | DNP | RC snubber; fit on first boards (sim/double_pulse.py), 0.3 W
R33,R40,R41,R60,R79 | 10k | Resistor_SMD:R_0402_1005Metric |  | 5
R42 | 100k | Resistor_SMD:R_0402_1005Metric |  | 1
R61,R62,R80 | 1k | Resistor_SMD:R_0402_1005Metric |  | 3
R70 | 680 | Resistor_SMD:R_0402_1005Metric |  | 1
R71,R76 | 120 | Resistor_SMD:R_0603_1608Metric |  | 2 |  | RX termination
R72-R75 | 33 | Resistor_SMD:R_0402_1005Metric |  | 4
R77,R78 | 100 | Resistor_SMD:R_0402_1005Metric |  | 2
RS1,RS3 | 0.5m | Resistor_SMD:R_Shunt_Vishay_WSK2512_6332Metric_T2.66mm | Vishay WSK2512 0.5 mOhm 1% (verify) | 2 |  | Kelvin 4-terminal, top side between the FETs
TH1 | 10k NTC | Resistor_SMD:R_0603_1608Metric | Murata NCP18XH103F03RB | 1 |  | Place between phase B FETs
U1 | LM5164DDAR | Package_SO:Texas_HSOP-8-1EP_3.9x4.9mm_P1.27mm | TI LM5164DDAR | 1 |  | 100 V, 1 A COT sync buck; 12 V rail for gate drive
U2 | TPS62163DSGR | Package_SON:Texas_DSG0008A_WSON-8-1EP_2x2mm_P0.5mm_EP0.9x1.6mm | TI TPS62163DSGR | 1 |  | Fixed 5.0 V, 1 A; FB tied to GND for fixed version
U3 | TLV75533PDBVR | Package_TO_SOT_SMD:SOT-23-5 | TI TLV75533PDBVR | 1
U4 | DRV8353SRTAR | Package_DFN_QFN:Texas_RHA0040B_VQFN-40-1EP_6x6mm_P0.5mm_EP4.15x4.15mm | TI DRV8353SRTAR | 1 |  | VM from 12 V rail so gate-drive losses do not scale with VBUS
U5 | STM32G474CEU6 | Package_DFN_QFN:QFN-48-1EP_7x7mm_P0.5mm_EP5.6x5.6mm | ST STM32G474CEU6 | 1 |  | 170 MHz M4F, HRTIM, FDCAN, 5x ADC
U6 | TCAN1044AVDR | Package_SO:SOIC-8_3.9x4.9mm_P1.27mm | TI TCAN1044AVDR | 1 |  | 8 Mbit/s CAN-FD, VIO 3.3 V; TJA1051T/3 pinout
U7 | AS5047P-ATSM | Package_SO:TSSOP-14_4.4x5mm_P0.65mm | ams OSRAM AS5047P-ATSM | 1 |  | 14-bit on-axis encoder, bottom side at rotation axis, same TSSOP-14 height as MD80
U8 | MAX3490EESA+ | Package_SO:SOIC-8_3.9x4.9mm_P1.27mm | Analog MAX3490EESA+ | 1 |  | Full-duplex RS-422 for AksIM-2 / Orbis
Y1 | 8MHz | Crystal:Crystal_SMD_3225-4Pin_3.2x2.5mm | Abracon ABM8-8.000MHZ-B2-T (verify CL) | 1 |  | HSE for FDCAN bit timing at 8 Mbit/s

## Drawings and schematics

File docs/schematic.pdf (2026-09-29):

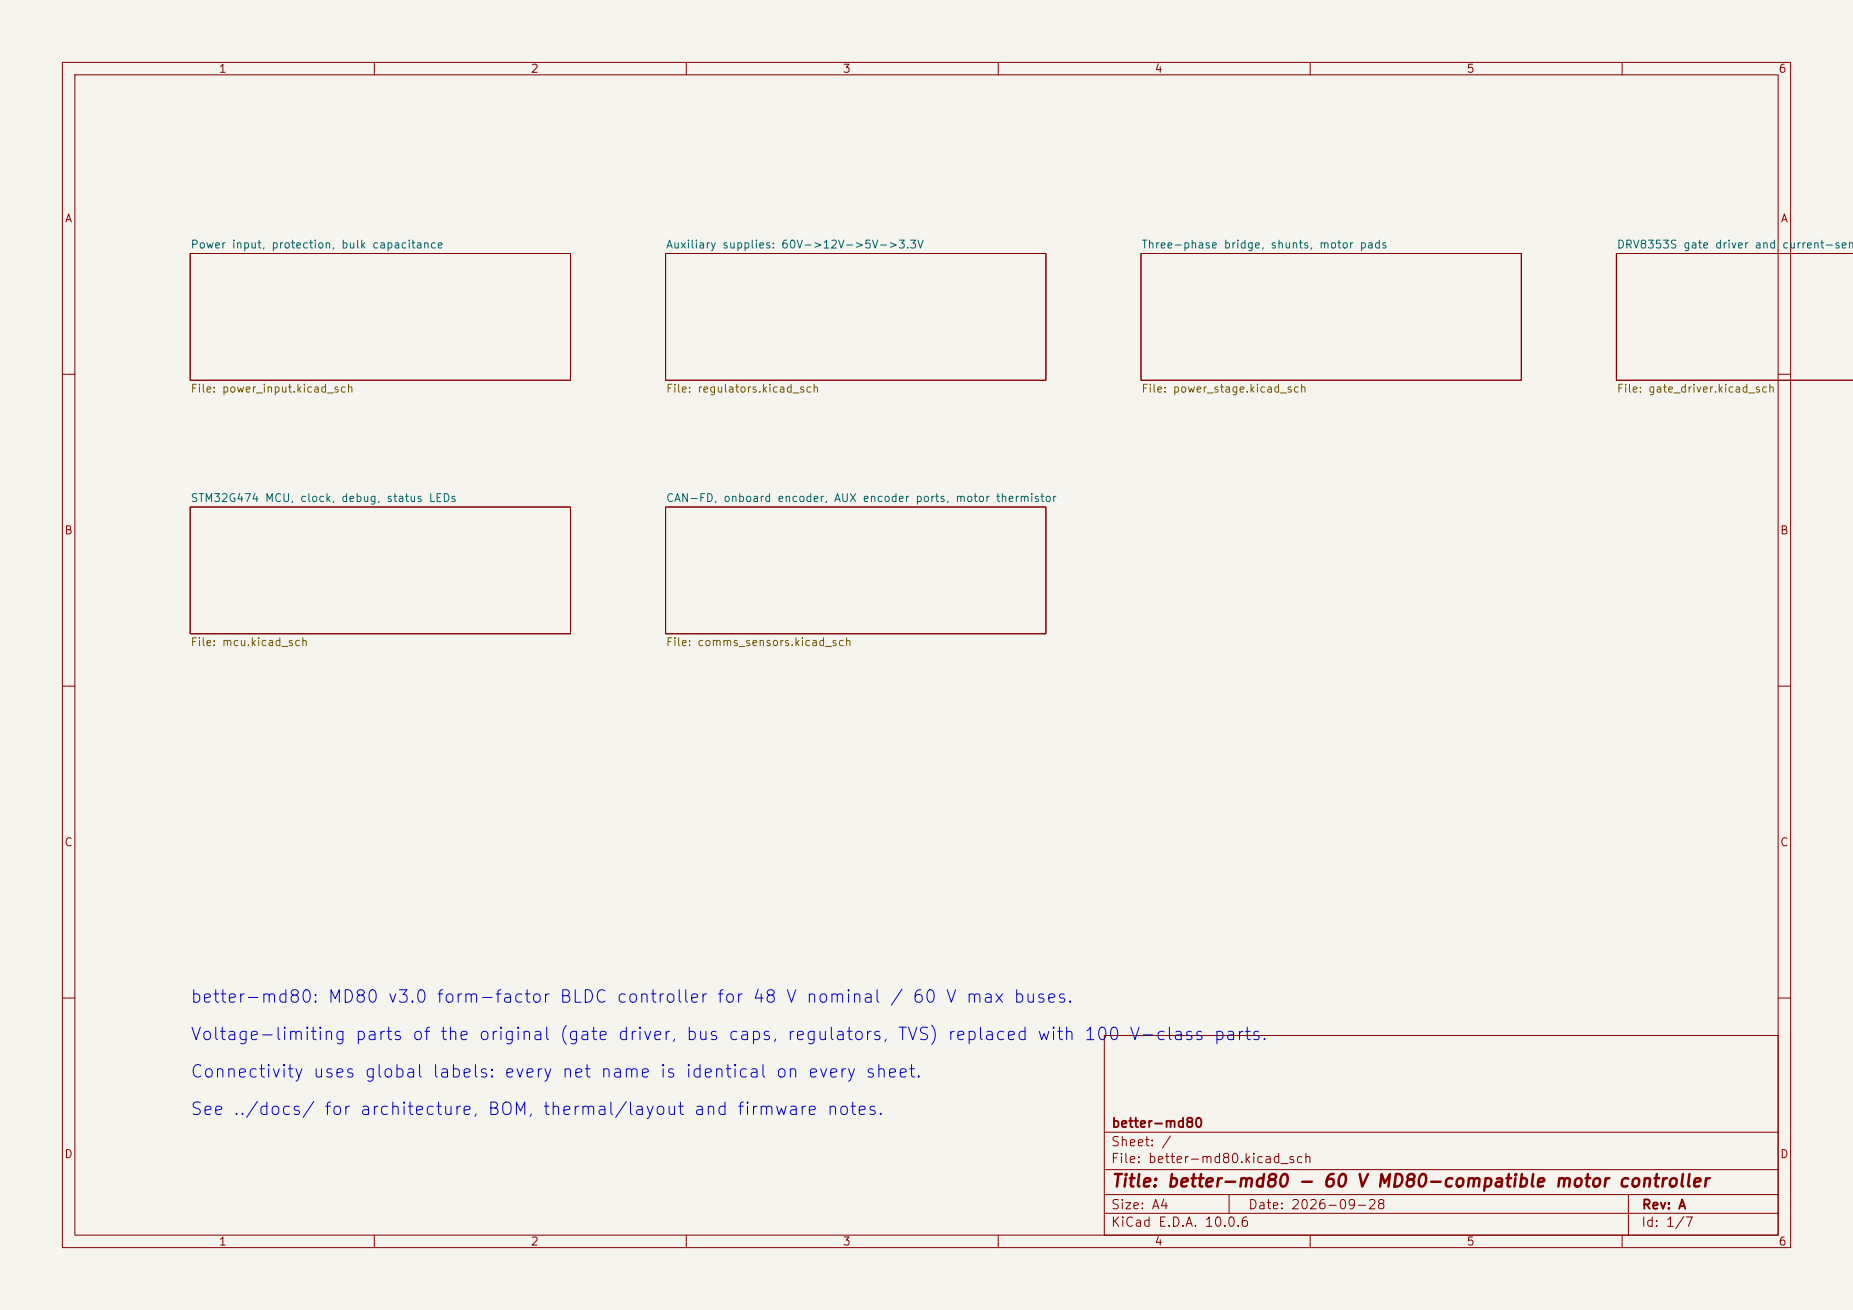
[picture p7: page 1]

CAN-FD, onboard encoder, AUX encoder ports, motor thermistor File: comms_sensors.kicad_sch Power input, protection, bulk capacitance

Three-phase bridge, shunts, motor pads File: power_stage.kicad_sch

better-md80: MD80 v3.0 form-factor BLDC controller for 48 V nominal / 60 V max buses.
Voltage-limiting parts of the original (gate driver, bus caps, regulators, TVS) replaced with 100 V-class parts.
Connectivity uses global labels: every net name is identical on every sheet.
See ../docs/ for architecture, BOM, thermal/layout and firmware notes.

better-md80
Sheet: /
File: better-md80.kicad_sch
Title: better-md80 - 60 V MD80-compatible motor controller

Size: A4 | Rev: A
KiCad E.D.A. 10.0.6 | Id: 1/7

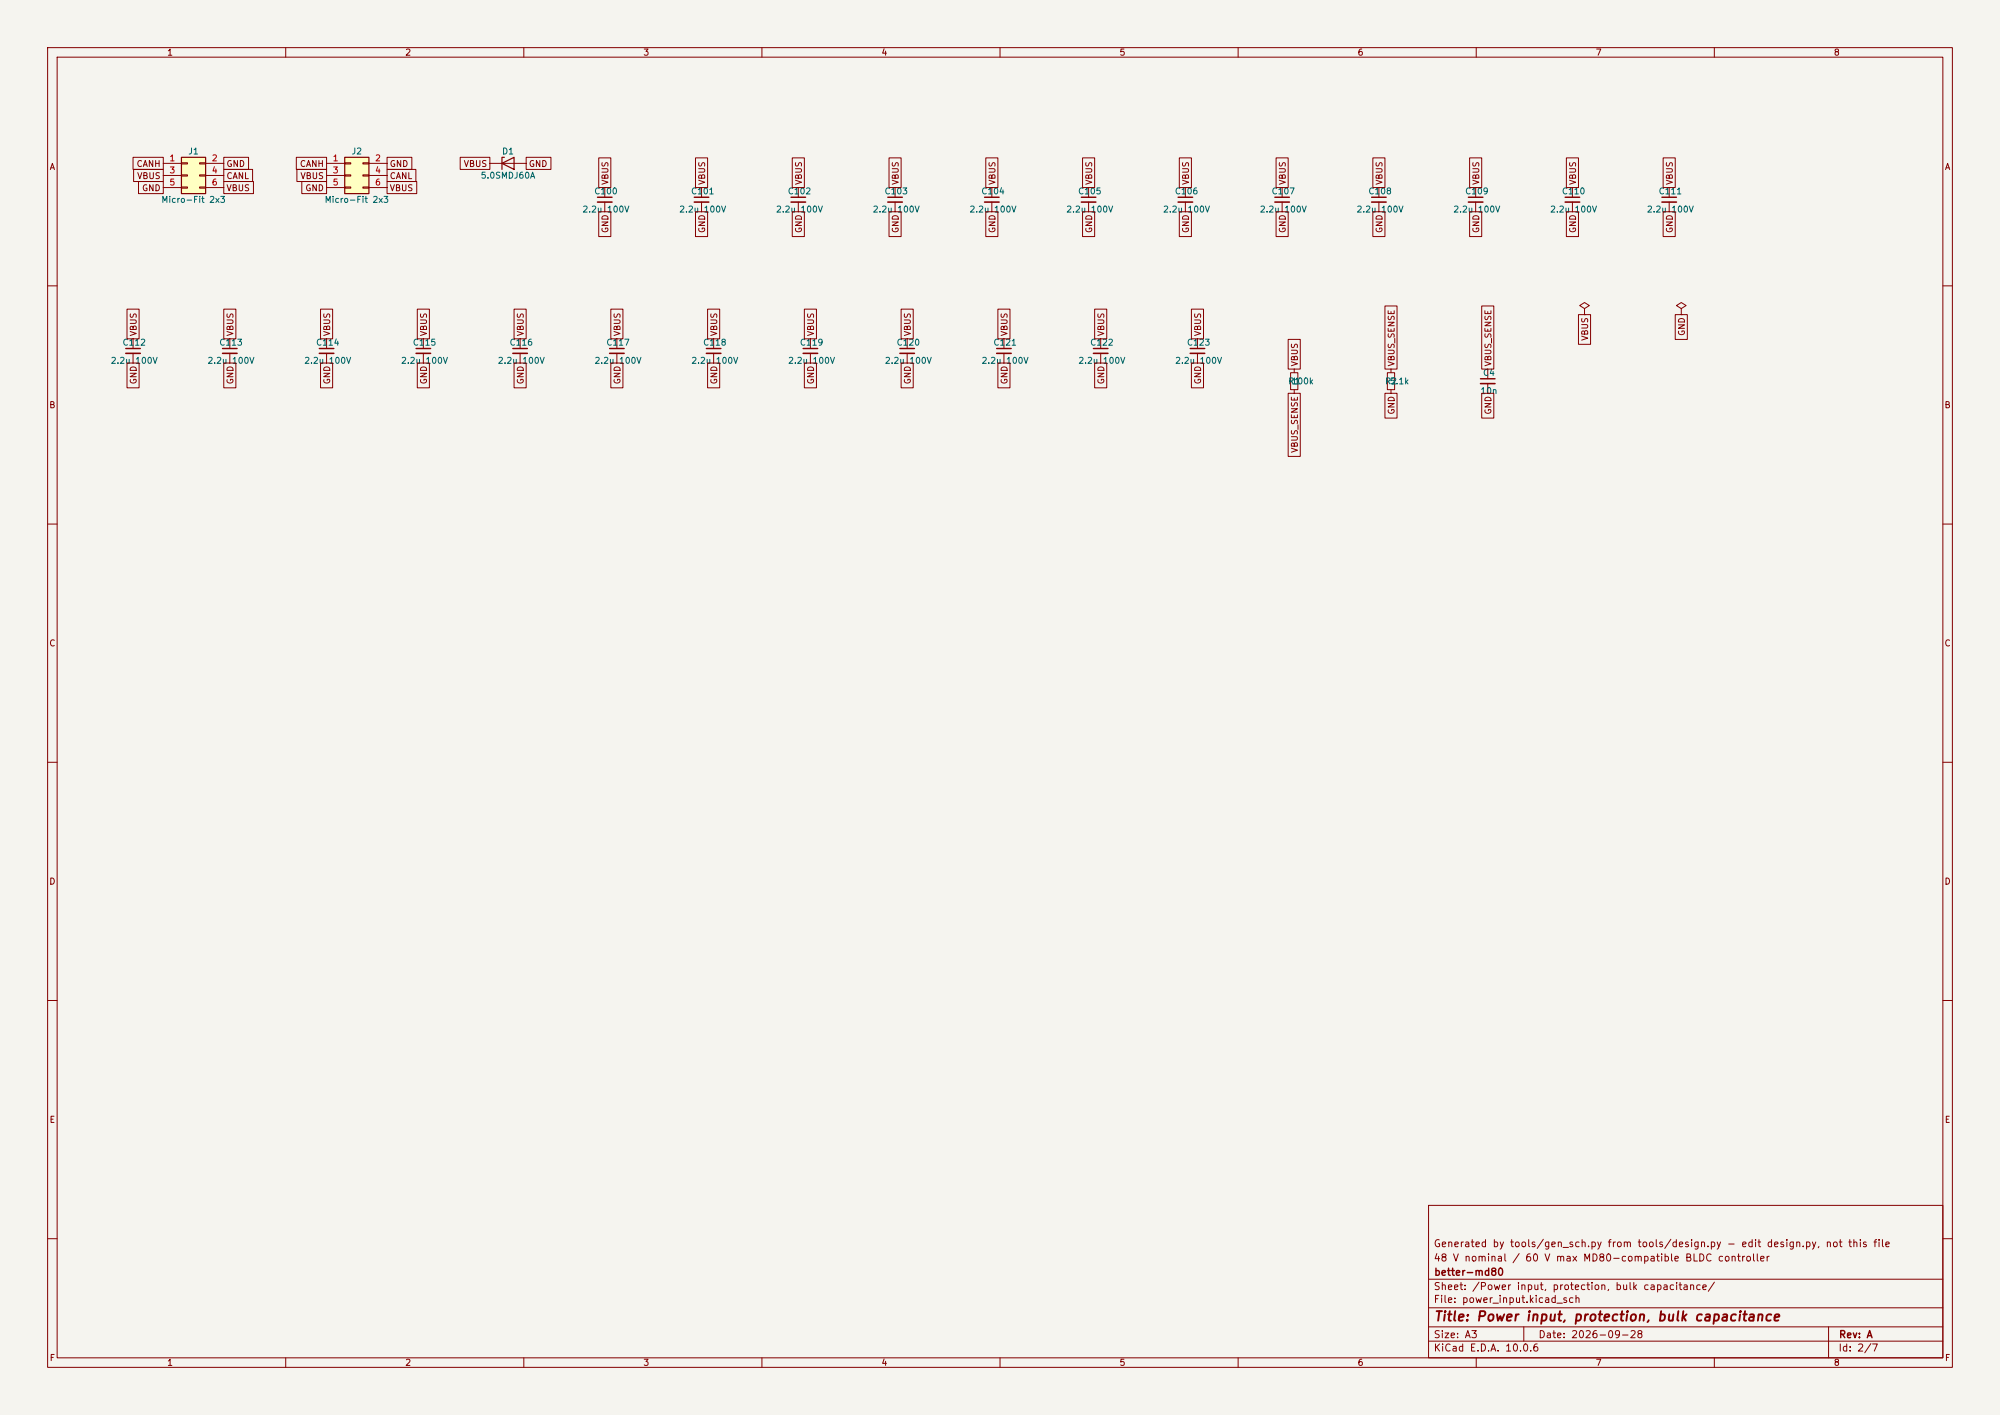
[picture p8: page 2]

Generated by tools/gen_sch.py from tools/design.py - edit design.py, not this file
48 V nominal / 60 V max MD80-compatible BLDC controller
better-md80
Sheet: /Power input, protection, bulk capacitance/
File: power_input.kicad_sch
Title: Power input, protection, bulk capacitance

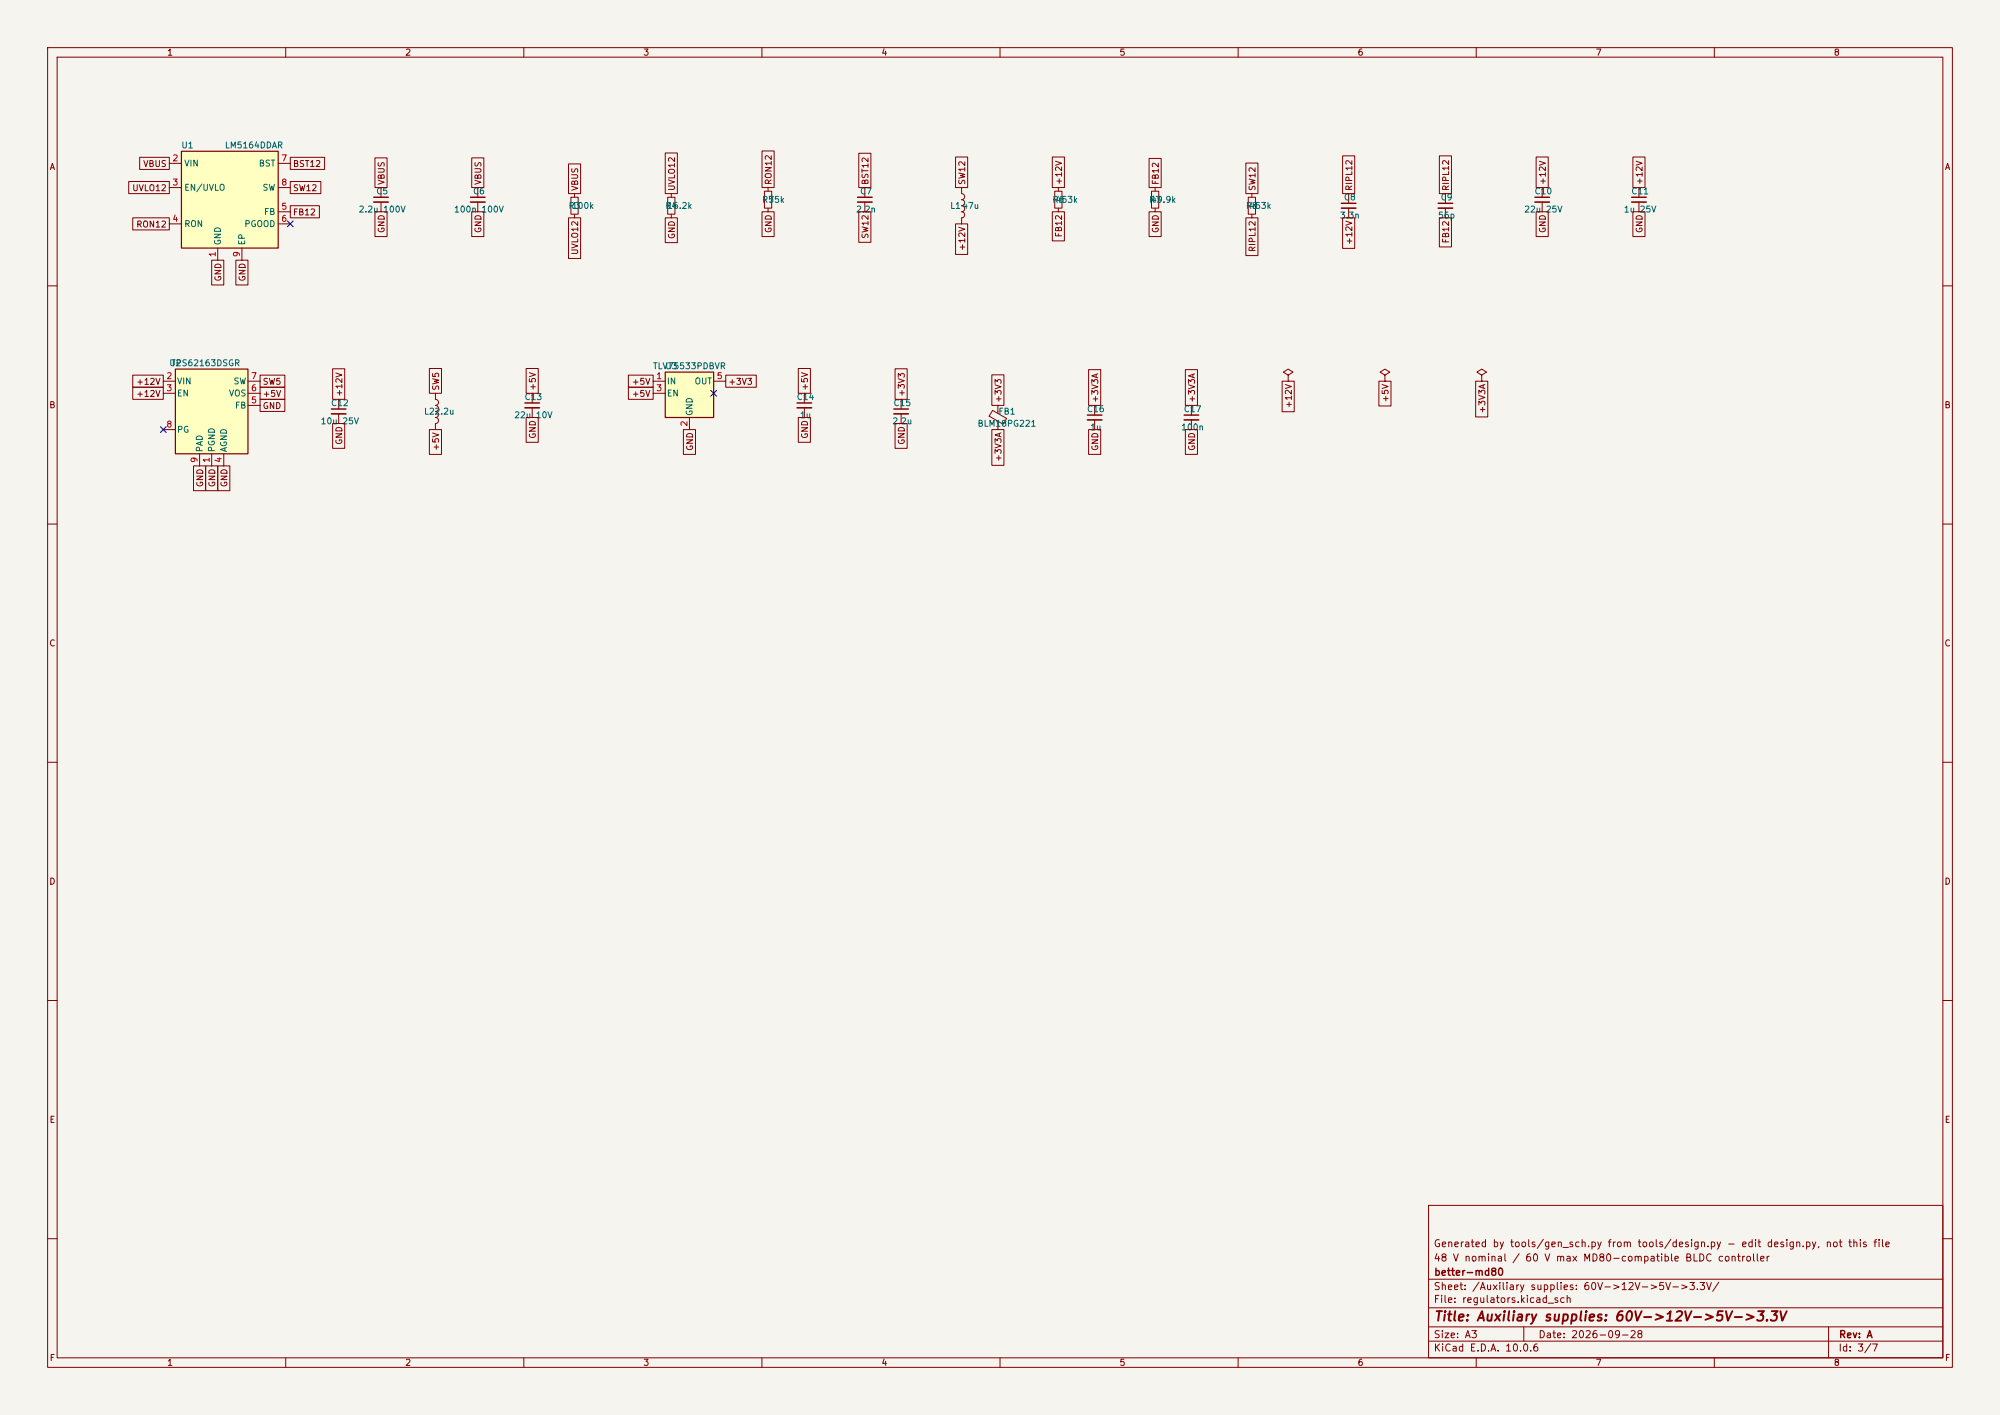
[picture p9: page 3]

Generated by tools/gen_sch.py from tools/design.py - edit design.py, not this file
48 V nominal / 60 V max MD80-compatible BLDC controller
better-md80
Sheet: /Auxiliary supplies: 60V->12V->5V->3.3V/
File: regulators.kicad_sch
Title: Auxiliary supplies: 60V->12V->5V->3.3V

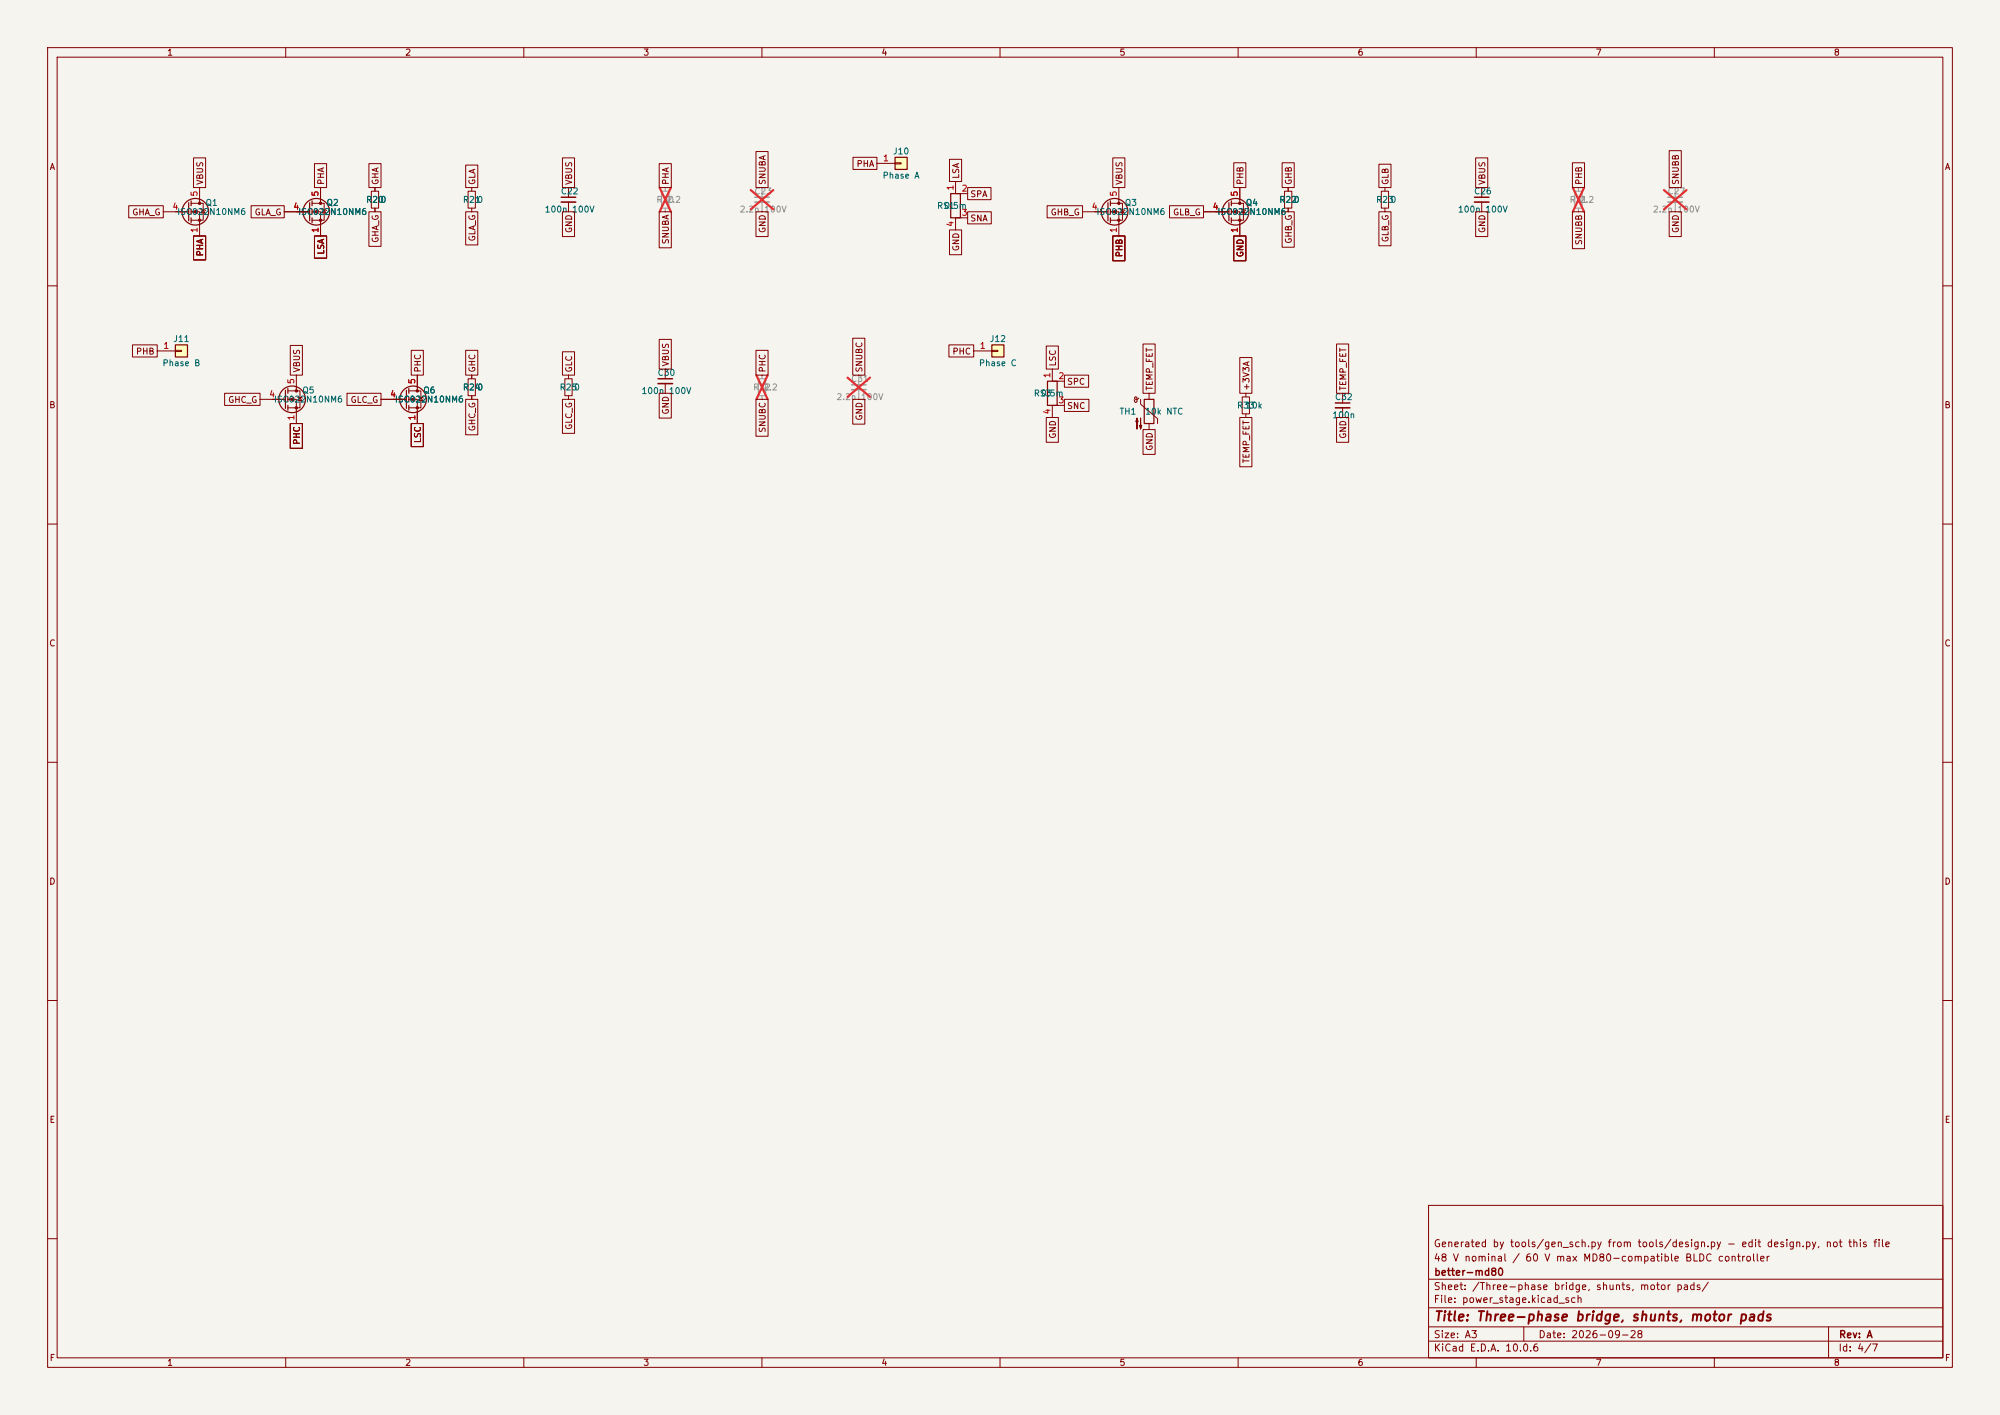
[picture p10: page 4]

Generated by tools/gen_sch.py from tools/design.py - edit design.py, not this file
48 V nominal / 60 V max MD80-compatible BLDC controller
better-md80
Sheet: /Three-phase bridge, shunts, motor pads/
File: power_stage.kicad_sch
Title: Three-phase bridge, shunts, motor pads

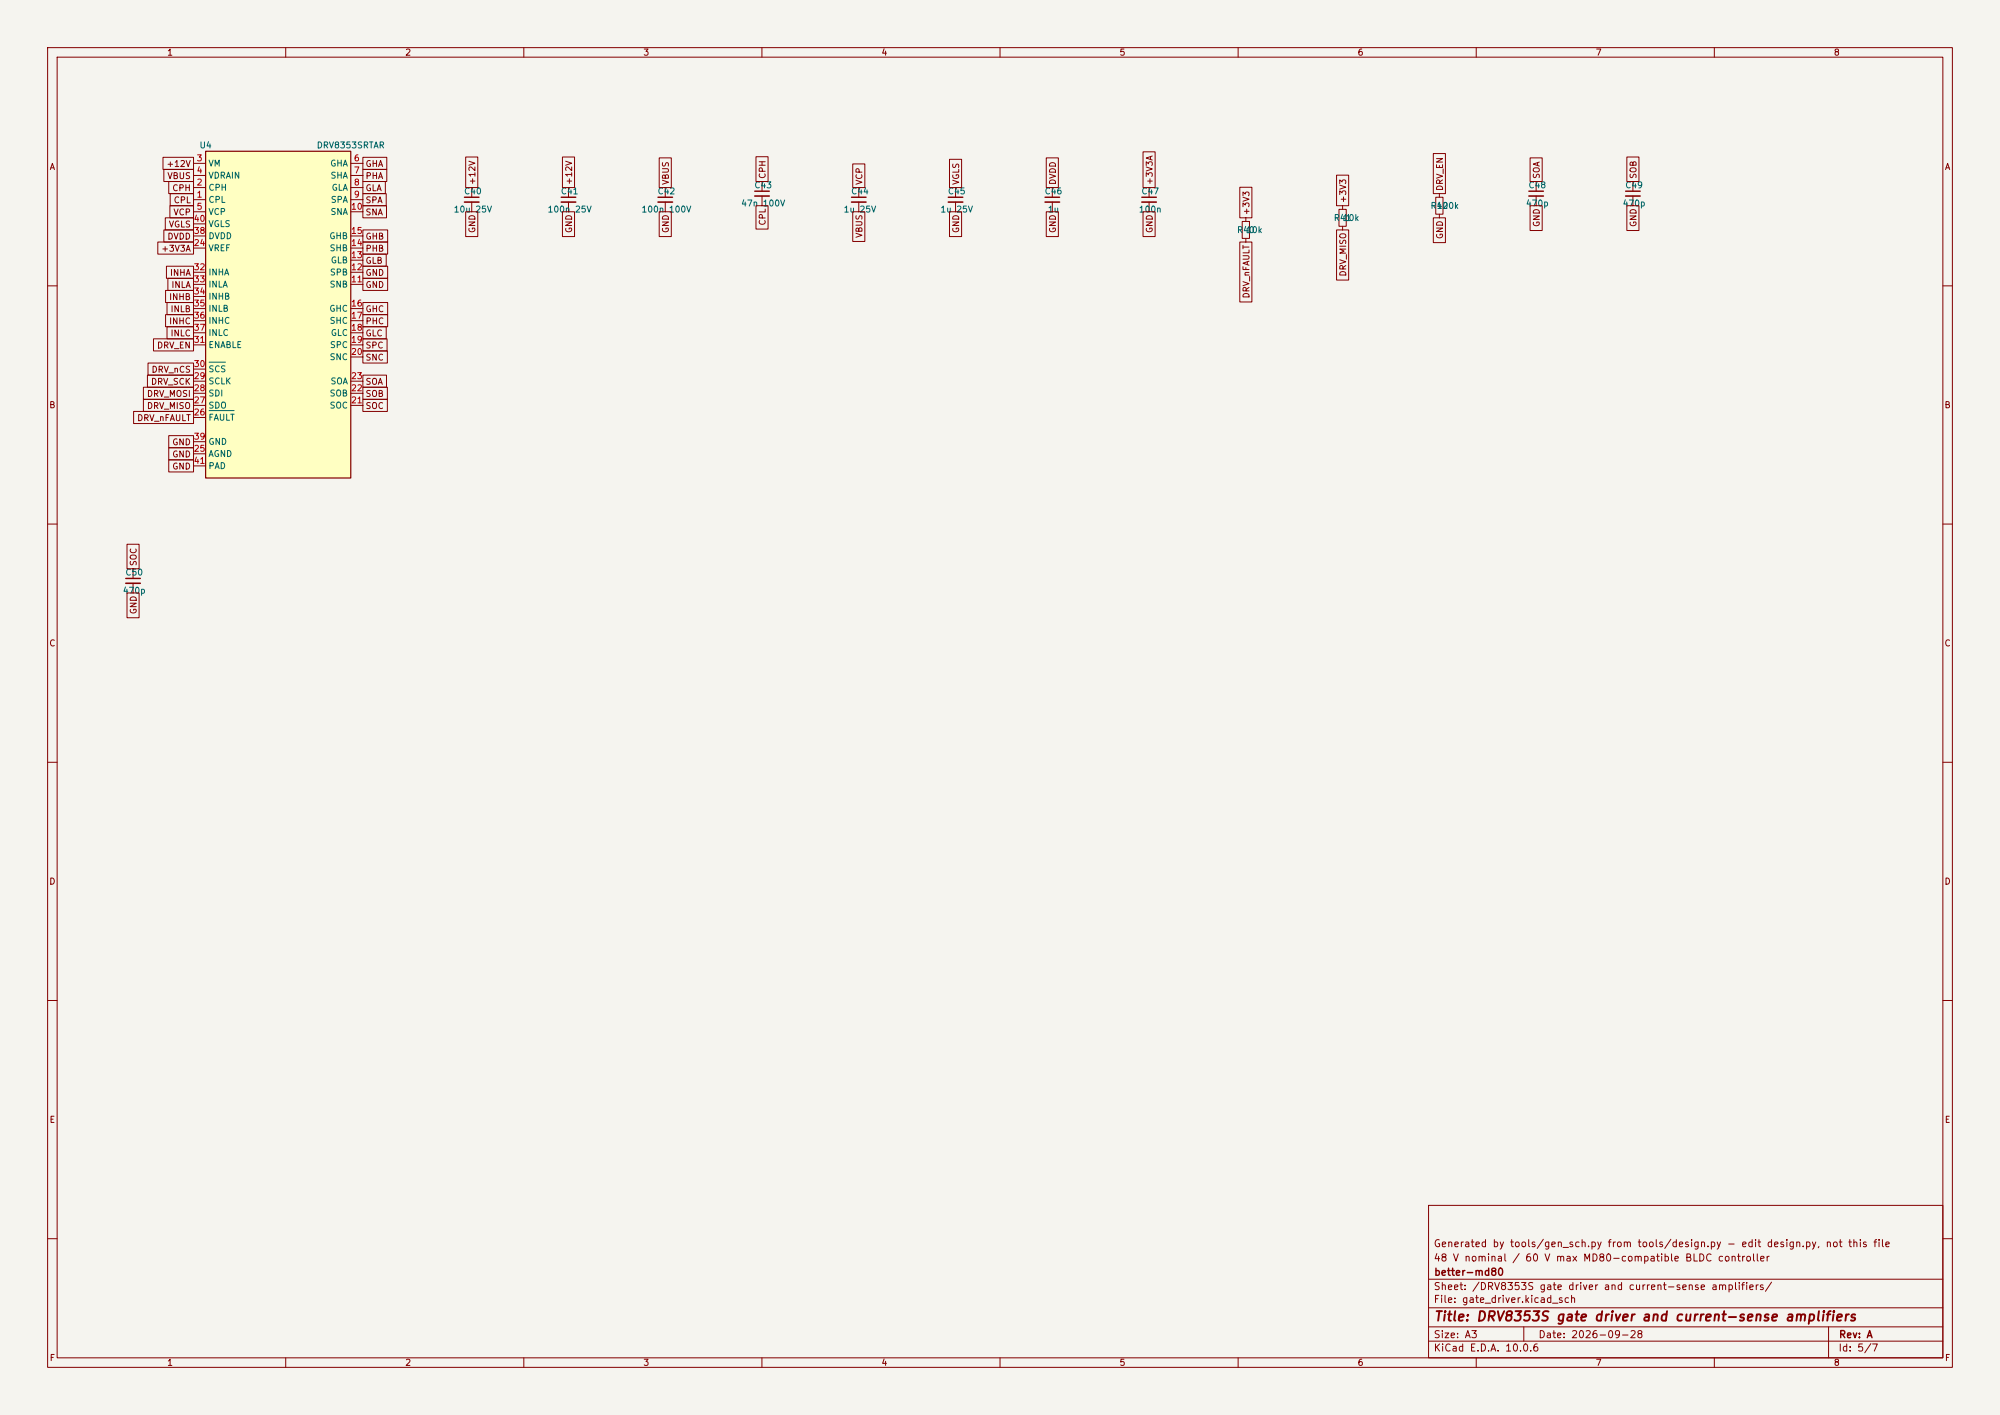
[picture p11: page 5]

SNB 11 SPB 12 GLB 13 SHB 14 GHB 15 GHC 16

FAULT 26 SDO 27 SDI 28 SCLK 29 SCS 30

Generated by tools/gen_sch.py from tools/design.py - edit design.py, not this file
48 V nominal / 60 V max MD80-compatible BLDC controller
better-md80
Sheet: /DRV8353S gate driver and current-sense amplifiers/
File: gate_driver.kicad_sch
Title: DRV8353S gate driver and current-sense amplifiers

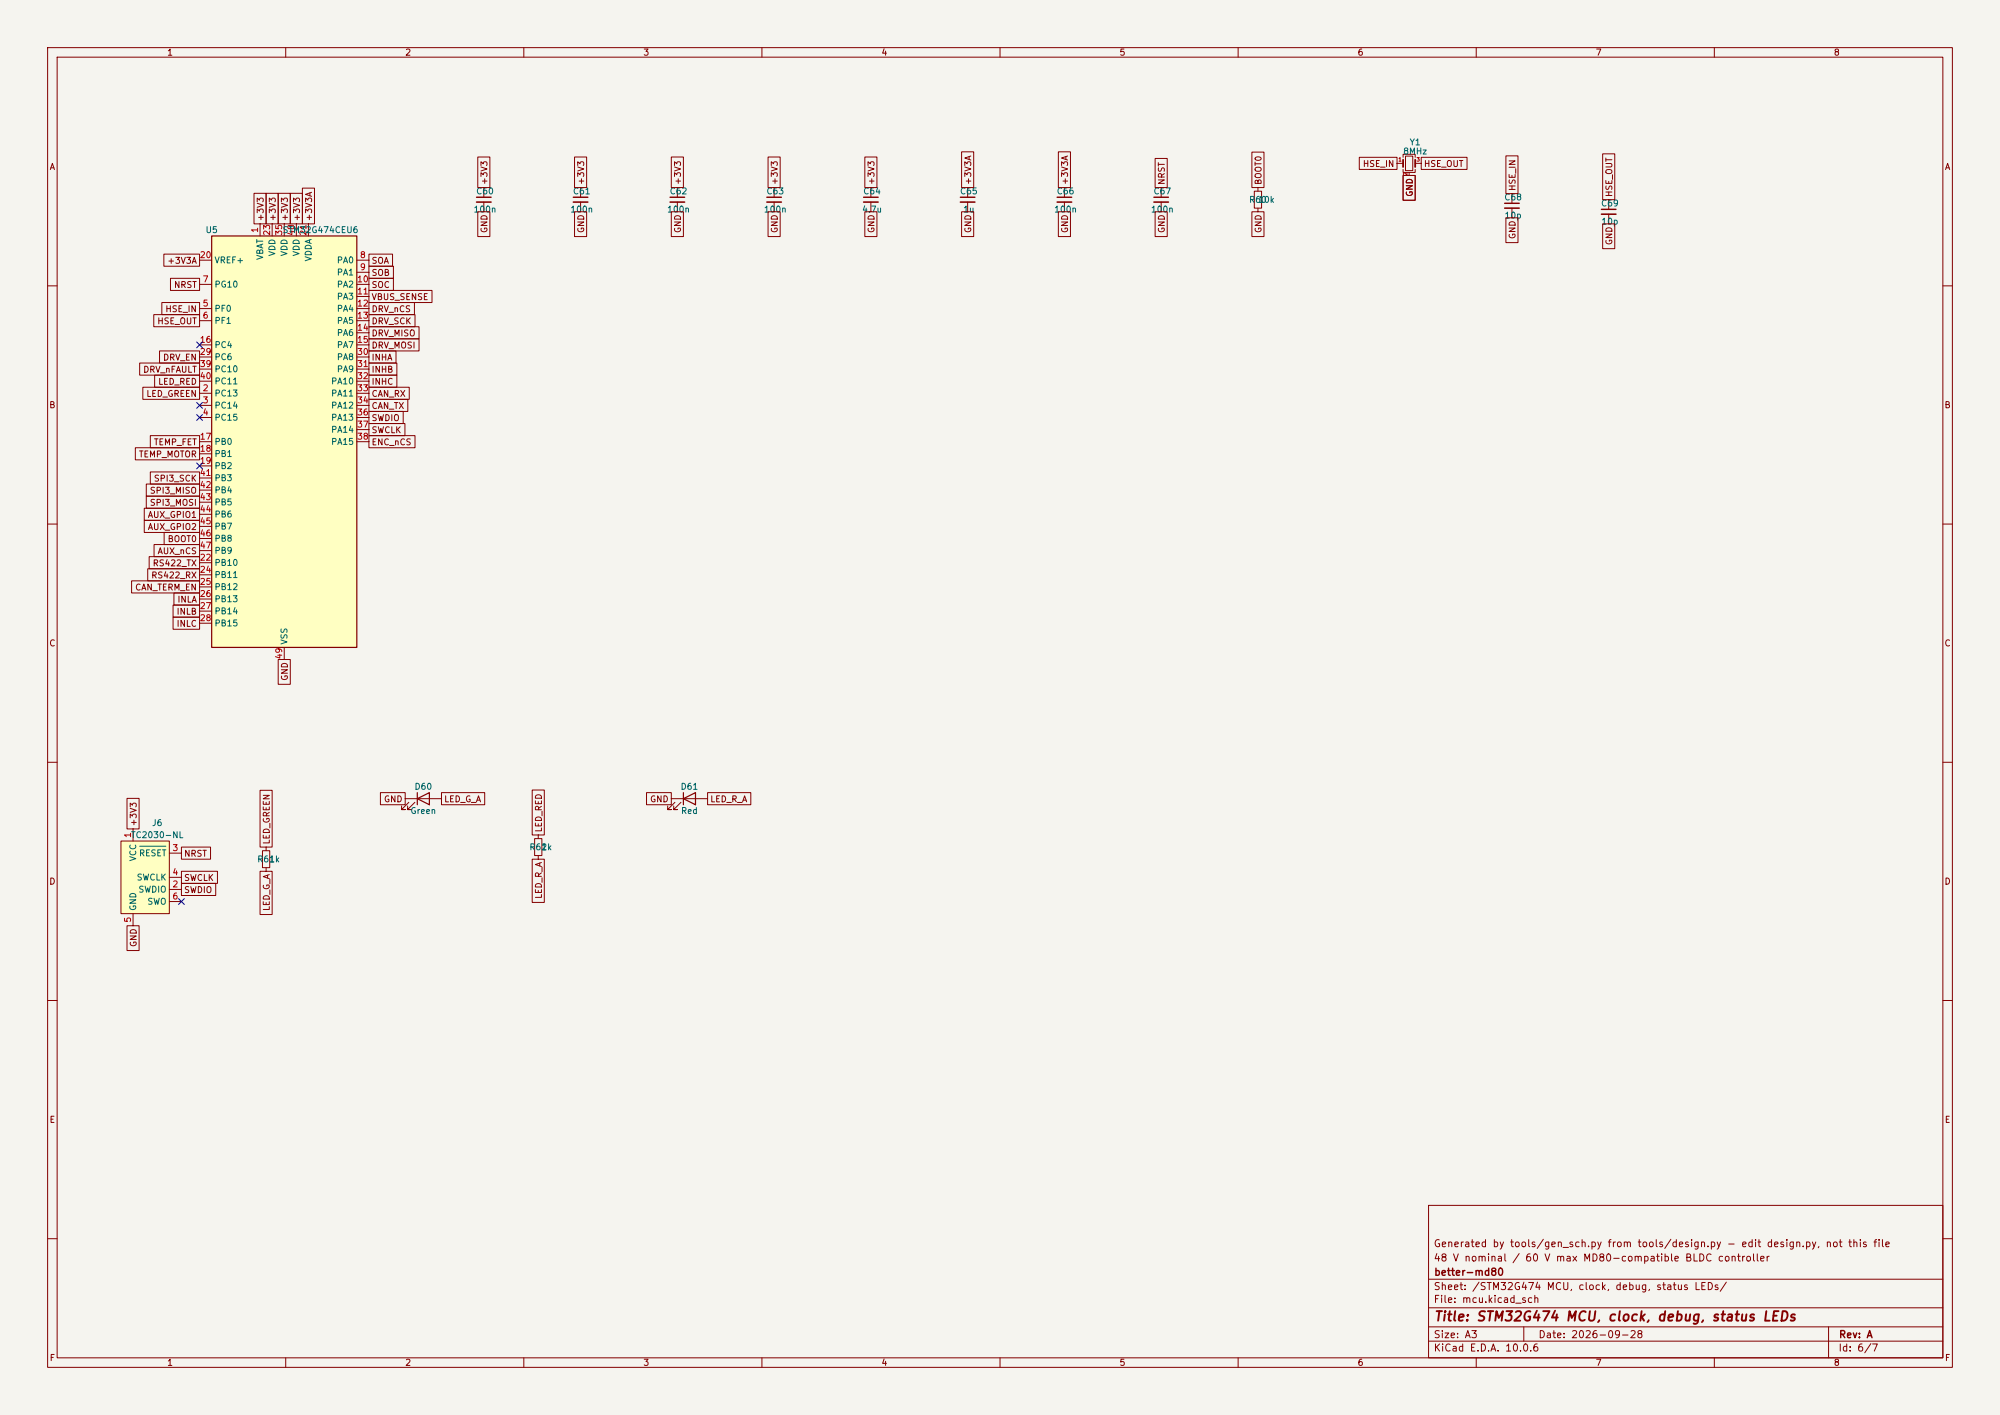
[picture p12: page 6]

Generated by tools/gen_sch.py from tools/design.py - edit design.py, not this file
48 V nominal / 60 V max MD80-compatible BLDC controller
better-md80
Sheet: /STM32G474 MCU, clock, debug, status LEDs/
File: mcu.kicad_sch
Title: STM32G474 MCU, clock, debug, status LEDs

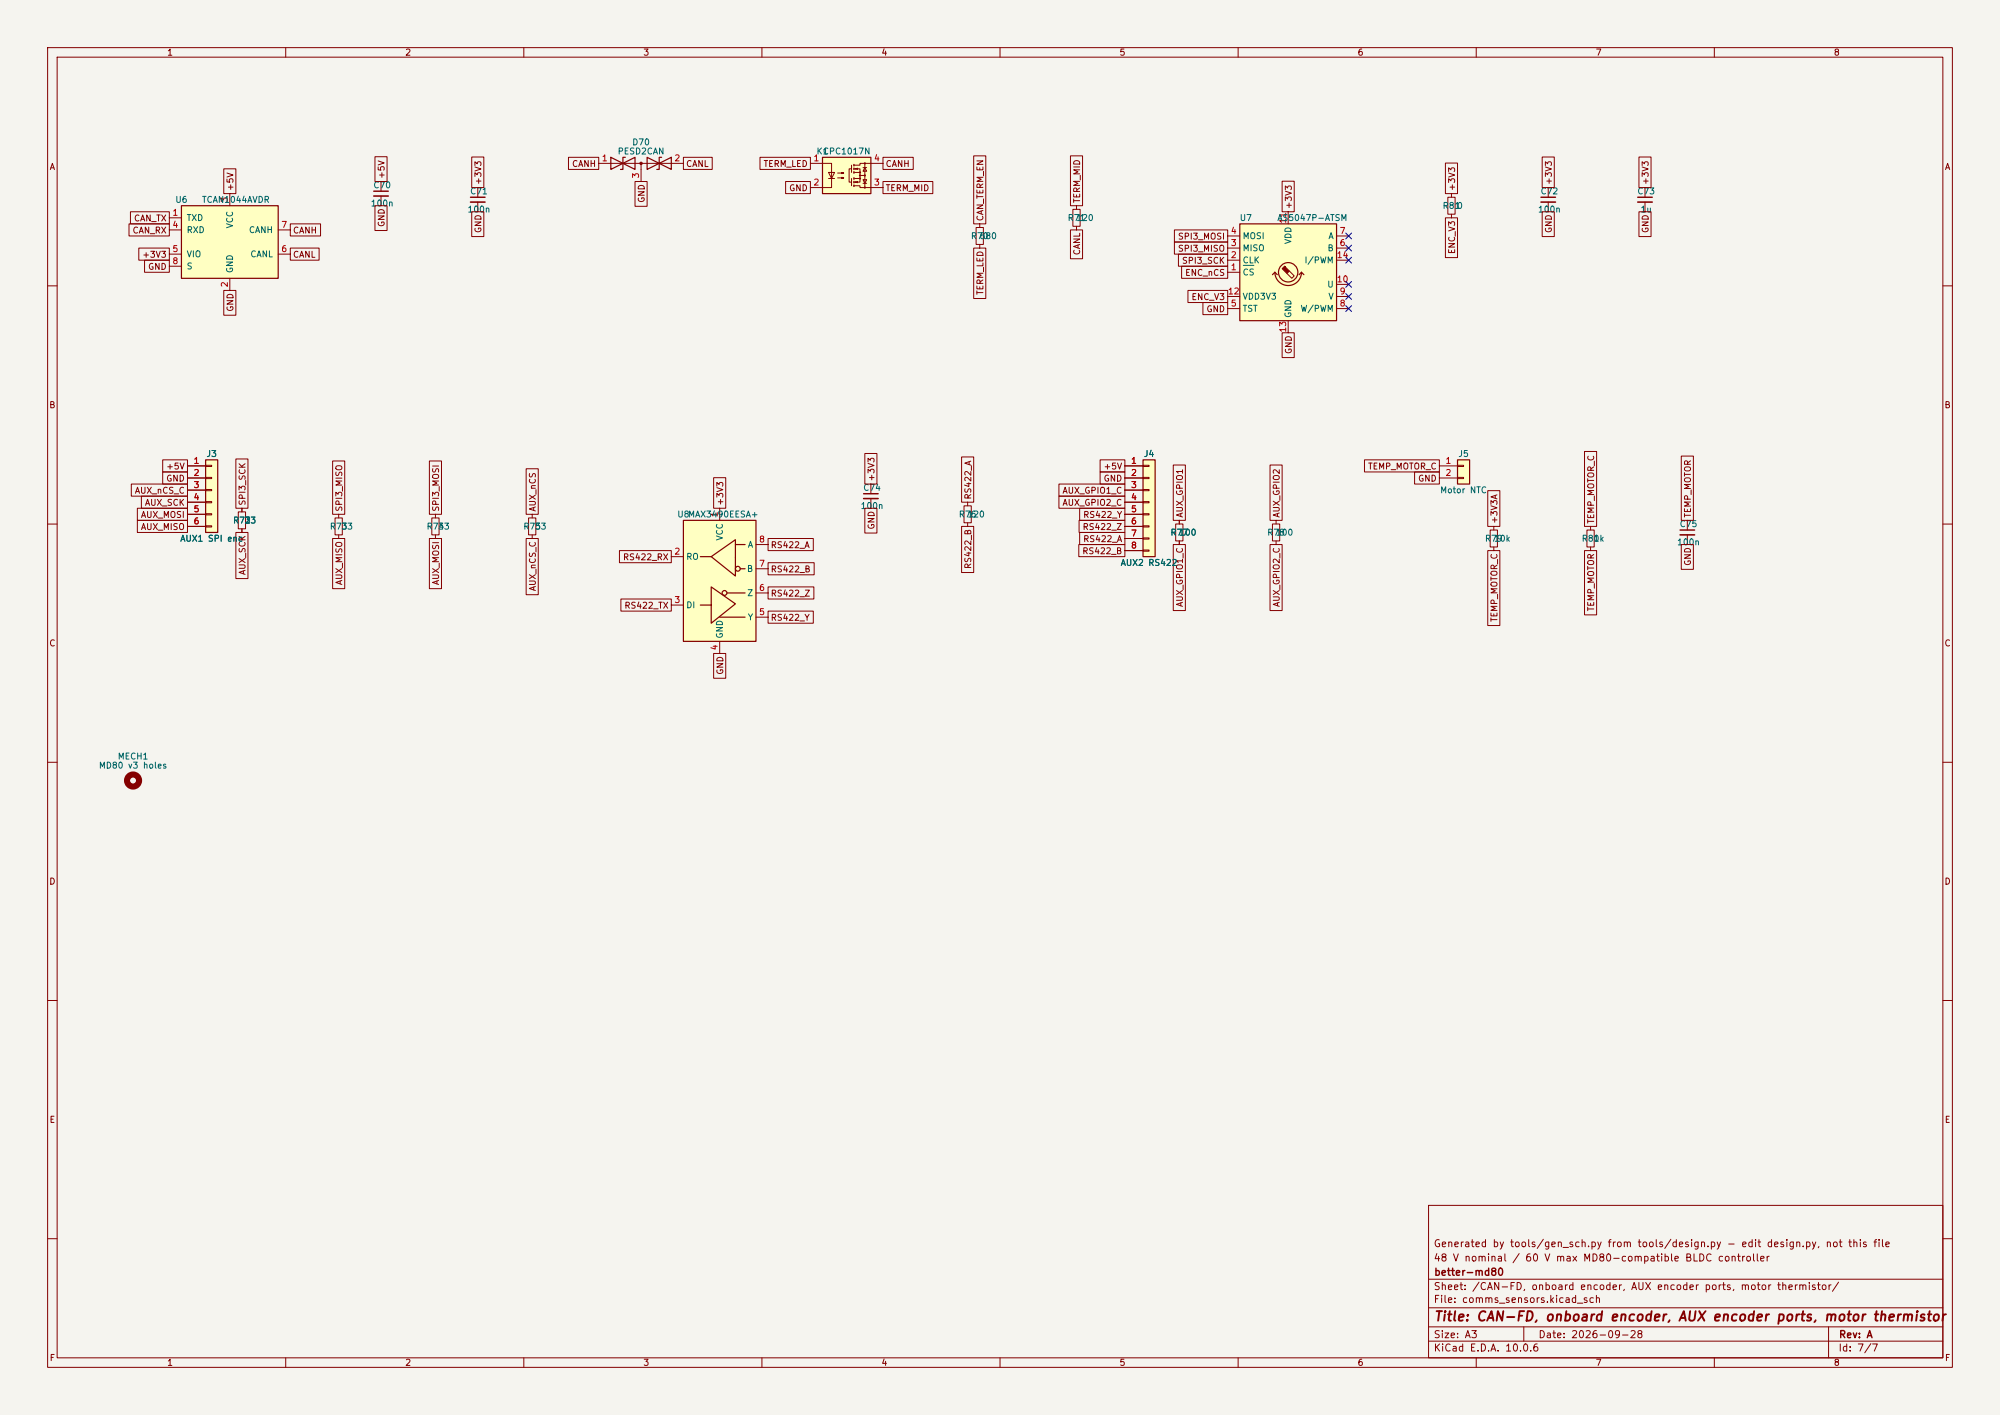
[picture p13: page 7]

Generated by tools/gen_sch.py from tools/design.py - edit design.py, not this file
48 V nominal / 60 V max MD80-compatible BLDC controller
better-md80
Sheet: /CAN-FD, onboard encoder, AUX encoder ports, motor thermistor/
File: comms_sensors.kicad_sch
Title: CAN-FD, onboard encoder, AUX encoder ports, motor thermistor

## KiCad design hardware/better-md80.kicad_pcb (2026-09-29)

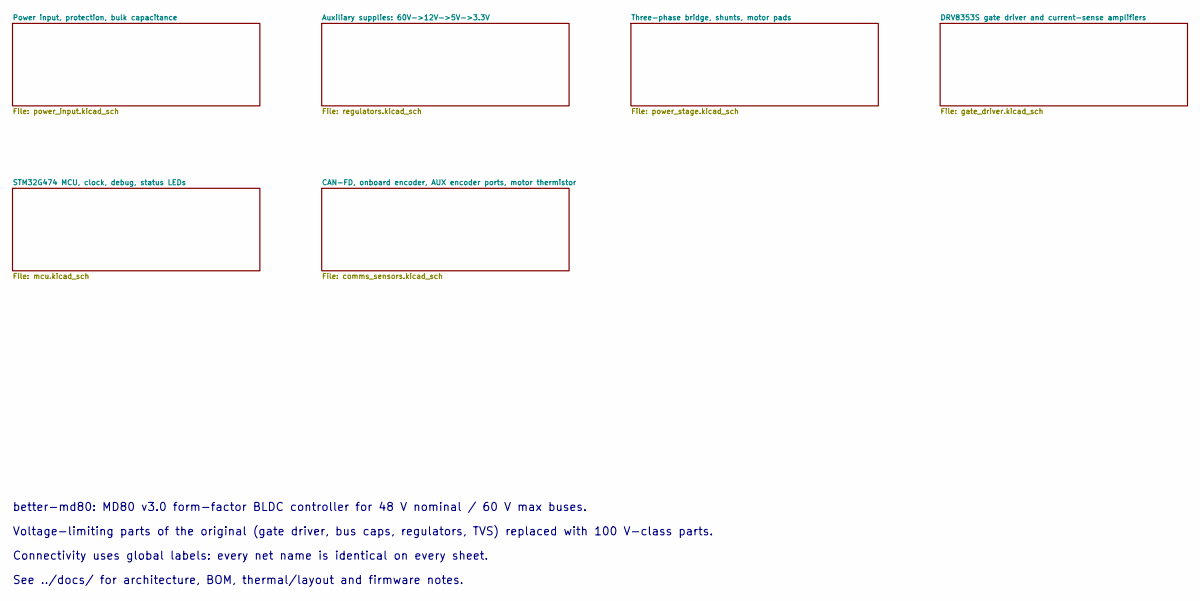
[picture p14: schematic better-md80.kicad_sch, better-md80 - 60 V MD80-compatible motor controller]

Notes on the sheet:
better-md80: MD80 v3.0 form-factor BLDC controller for 48 V nominal / 60 V max buses.
Connectivity uses global labels: every net name is identical on every sheet.
Voltage-limiting parts of the original (gate driver, bus caps, regulators, TVS) replaced with 100 V-class parts.
See ../docs/ for architecture, BOM, thermal/layout and firmware notes.

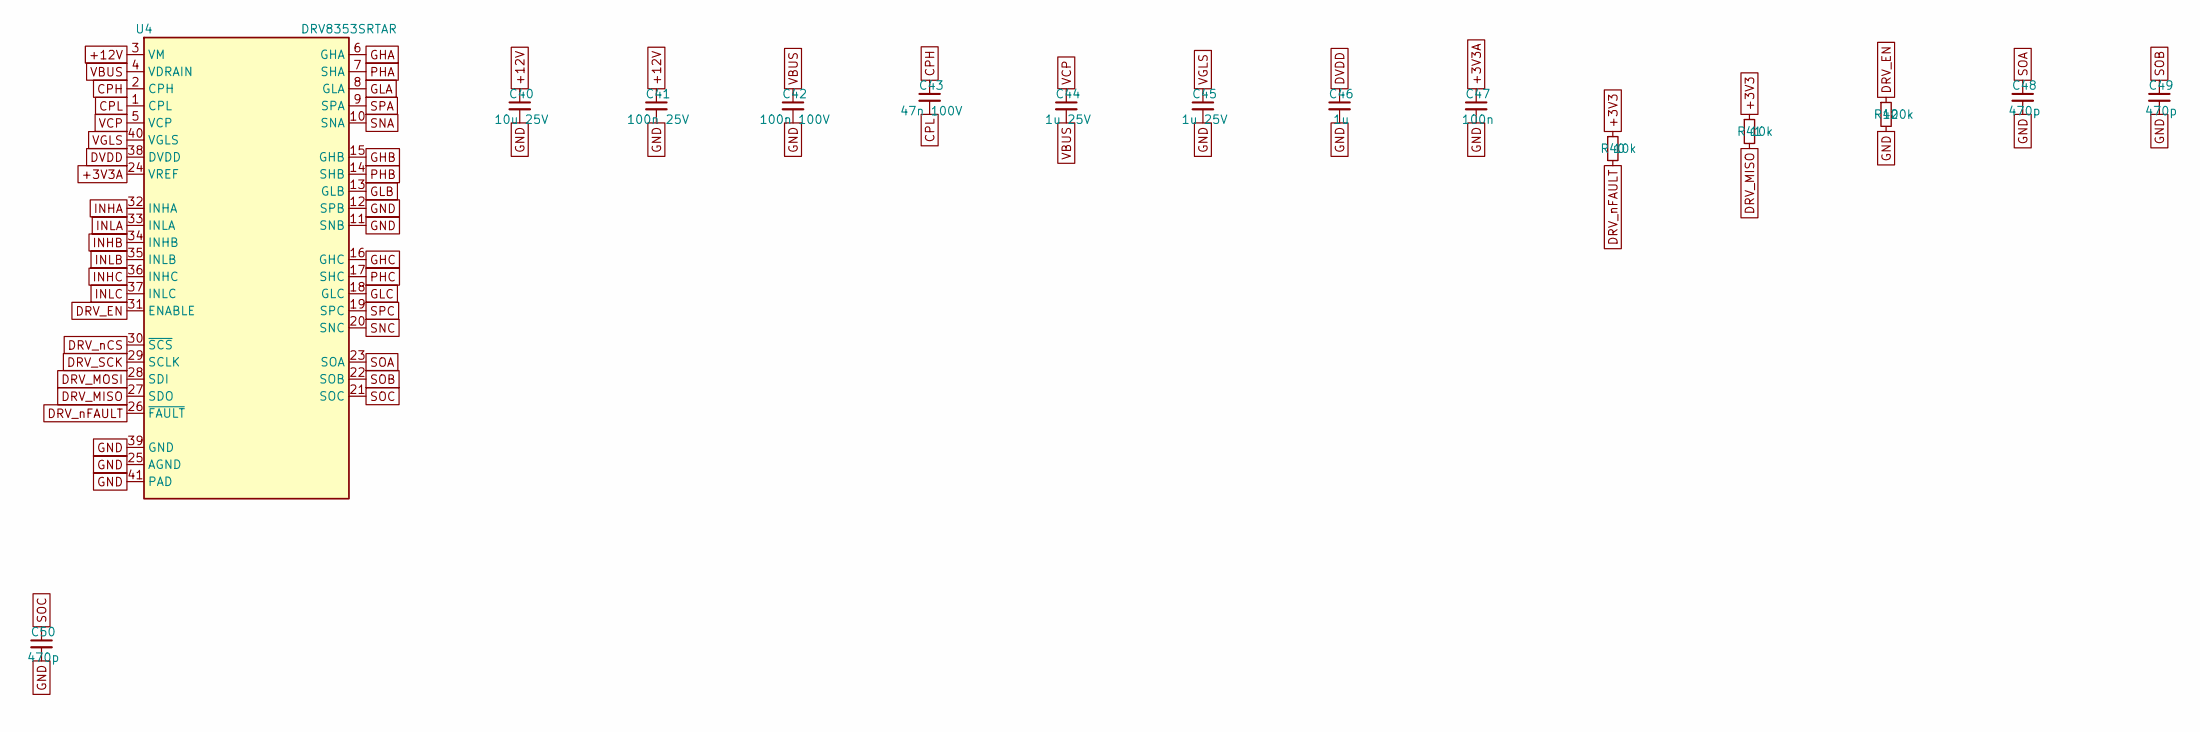
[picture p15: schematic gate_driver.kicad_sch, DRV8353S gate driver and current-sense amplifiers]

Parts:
C40: 10u 25V; C_0805_2012Metric
C41: 100n 25V; C_0402_1005Metric
C42: 100n 100V; C_0603_1608Metric; MPN Murata GRM188R72A104KA35D
C43: 47n 100V; C_0603_1608Metric; MPN Murata GRM188R72A473KA01D (verify)
C44, C45: 1u 25V; C_0603_1608Metric
C46: 1u; C_0402_1005Metric
C47: 100n; C_0402_1005Metric
C48, C49, C50: 470p; C_0402_1005Metric
R40, R41: 10k; R_0402_1005Metric
R42: 100k; R_0402_1005Metric
U4: DRV8353SRTAR; Texas_RHA0040B_VQFN-40-1EP_6x6mm_P0.5mm_EP4.15x4.15mm; MPN TI DRV8353SRTAR

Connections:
+3V3: R40.1, R41.1; also elsewhere on the board
+3V3A: C47.1, U4.24 (VREF); also elsewhere on the board
+12V: C40.1, C41.1, U4.3 (VM); also elsewhere on the board
CPH: C43.1, U4.2 (CPH)
CPL: C43.2, U4.1 (CPL)
DRV_EN: R42.1, U4.31 (ENABLE); also elsewhere on the board
DRV_MISO: R41.2, U4.27 (SDO); also elsewhere on the board
DRV_MOSI: U4.28 (SDI); also elsewhere on the board
DRV_SCK: U4.29 (SCLK); also elsewhere on the board
DRV_nCS: U4.30 (~SCS); also elsewhere on the board
DRV_nFAULT: R40.2, U4.26 (~FAULT); also elsewhere on the board
DVDD: C46.1, U4.38 (DVDD)
GHA: U4.6 (GHA); also elsewhere on the board
GHB: U4.15 (GHB); also elsewhere on the board
GHC: U4.16 (GHC); also elsewhere on the board
GLA: U4.8 (GLA); also elsewhere on the board
GLB: U4.13 (GLB); also elsewhere on the board
GLC: U4.18 (GLC); also elsewhere on the board
GND: C40.2, C41.2, C42.2, C45.2, C46.2, C47.2, C48.2, C49.2, C50.2, R42.2, U4.11 (SNB), U4.12 (SPB), U4.25 (AGND), U4.39 (GND), U4.41 (PAD); also elsewhere on the board
INHA: U4.32 (INHA); also elsewhere on the board
INHB: U4.34 (INHB); also elsewhere on the board
INHC: U4.36 (INHC); also elsewhere on the board
INLA: U4.33 (INLA); also elsewhere on the board
INLB: U4.35 (INLB); also elsewhere on the board
INLC: U4.37 (INLC); also elsewhere on the board
PHA: U4.7 (SHA); also elsewhere on the board
PHB: U4.14 (SHB); also elsewhere on the board
PHC: U4.17 (SHC); also elsewhere on the board
SNA: U4.10 (SNA); also elsewhere on the board
SNC: U4.20 (SNC); also elsewhere on the board
SOA: C48.1, U4.23 (SOA); also elsewhere on the board
SOB: C49.1, U4.22 (SOB); also elsewhere on the board
SOC: C50.1, U4.21 (SOC); also elsewhere on the board
SPA: U4.9 (SPA); also elsewhere on the board
SPC: U4.19 (SPC); also elsewhere on the board
VBUS: C42.1, C44.2, U4.4 (VDRAIN); also elsewhere on the board
VCP: C44.1, U4.5 (VCP)
VGLS: C45.1, U4.40 (VGLS)

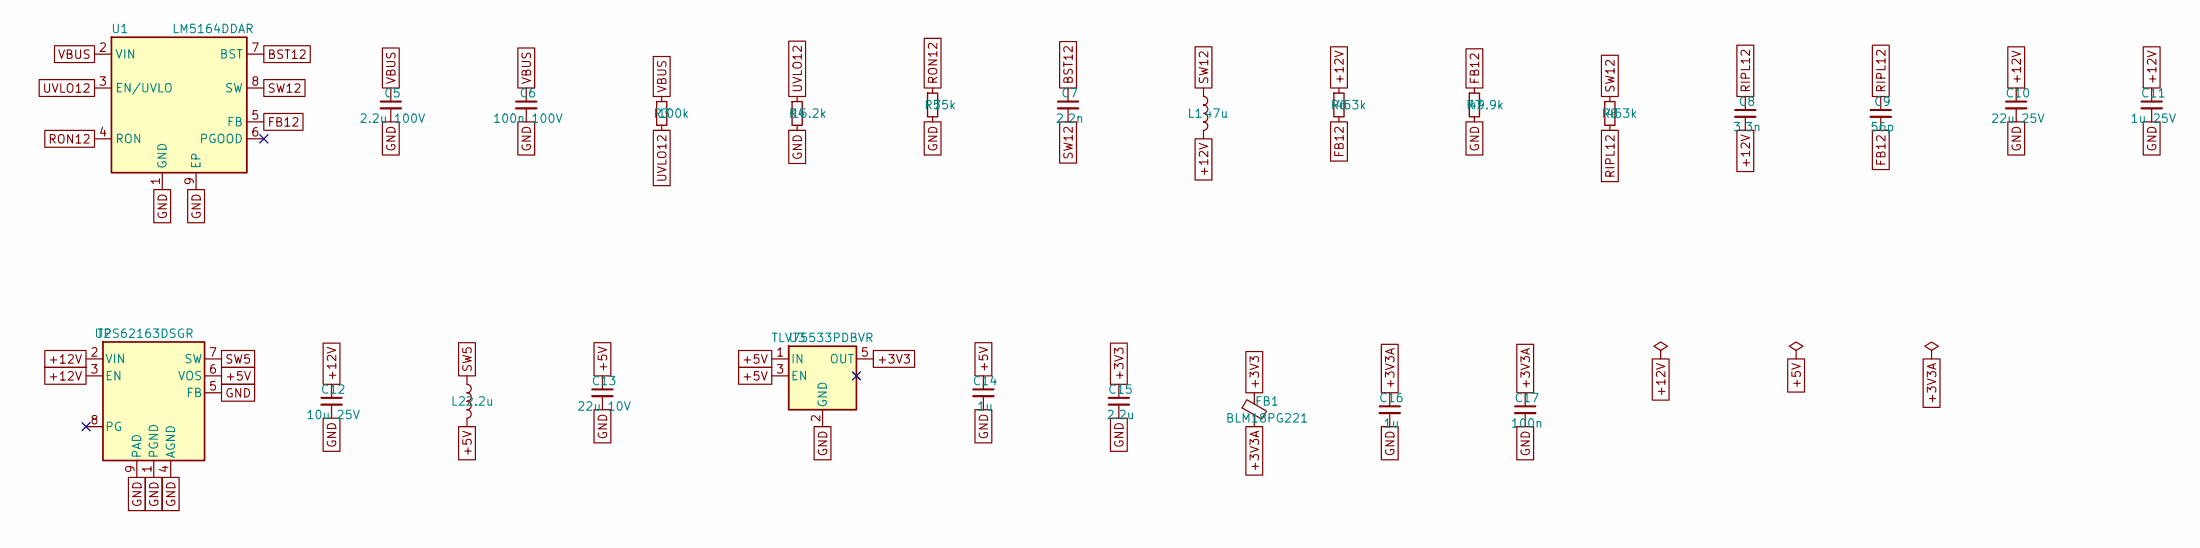
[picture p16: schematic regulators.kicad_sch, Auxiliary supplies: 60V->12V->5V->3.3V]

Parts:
C5: 2.2u 100V; C_1206_3216Metric; MPN TDK C3216X7S2A225K160AB
C6: 100n 100V; C_0603_1608Metric; MPN Murata GRM188R72A104KA35D
C7: 2.2n; C_0402_1005Metric
C8: 3.3n; C_0402_1005Metric
C9: 56p; C_0402_1005Metric
C10: 22u 25V; C_1210_3225Metric; MPN Taiyo Yuden TMK325B7226KMHT
C11: 1u 25V; C_0603_1608Metric
C12: 10u 25V; C_0805_2012Metric
C13: 22u 10V; C_0805_2012Metric
C14, C16: 1u; C_0402_1005Metric
C15: 2.2u; C_0603_1608Metric
C17: 100n; C_0402_1005Metric
FB1: BLM18PG221; L_0603_1608Metric; MPN Murata BLM18PG221SN1D
L1: 47u; L_Bourns-SRN4018; MPN Bourns SRN4018-470M (verify Isat)
L2: 2.2u; L_1008_2520Metric; MPN Murata DFE252012F-2R2M
R3: 100k; R_0603_1608Metric
R4: 16.2k; R_0402_1005Metric
R5: 75k; R_0402_1005Metric
R6: 453k; R_0402_1005Metric
R7: 49.9k; R_0402_1005Metric
R8: 453k; R_0603_1608Metric
U1: LM5164DDAR; Texas_HSOP-8-1EP_3.9x4.9mm_P1.27mm; MPN TI LM5164DDAR
U2: TPS62163DSGR; Texas_DSG0008A_WSON-8-1EP_2x2mm_P0.5mm_EP0.9x1.6mm; MPN TI TPS62163DSGR
U3: TLV75533PDBVR; SOT-23-5; MPN TI TLV75533PDBVR

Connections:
+3V3: C15.1, FB1.1, U3.5 (OUT); also elsewhere on the board
+3V3A: C16.1, C17.1, FB1.2; also elsewhere on the board
+5V: C13.1, C14.1, L2.2, U2.6 (VOS), U3.1 (IN), U3.3 (EN); also elsewhere on the board
+12V: C8.2, C10.1, C11.1, C12.1, L1.2, R6.1, U2.2 (VIN), U2.3 (EN); also elsewhere on the board
BST12: C7.1, U1.7 (BST)
FB12: C9.2, R6.2, R7.1, U1.5 (FB)
GND: C5.2, C6.2, C10.2, C11.2, C12.2, C13.2, C14.2, C15.2, C16.2, C17.2, R4.2, R5.2, R7.2, U1.1 (GND), U1.9 (EP), U2.1 (PGND), U2.4 (AGND), U2.5 (FB), U2.9 (PAD), U3.2 (GND); also elsewhere on the board
RIPL12: C8.1, C9.1, R8.2
RON12: R5.1, U1.4 (RON)
SW5: L2.1, U2.7 (SW)
SW12: C7.2, L1.1, R8.1, U1.8 (SW)
UVLO12: R3.2, R4.1, U1.3 (EN/UVLO)
VBUS: C5.1, C6.1, R3.1, U1.2 (VIN); also elsewhere on the board

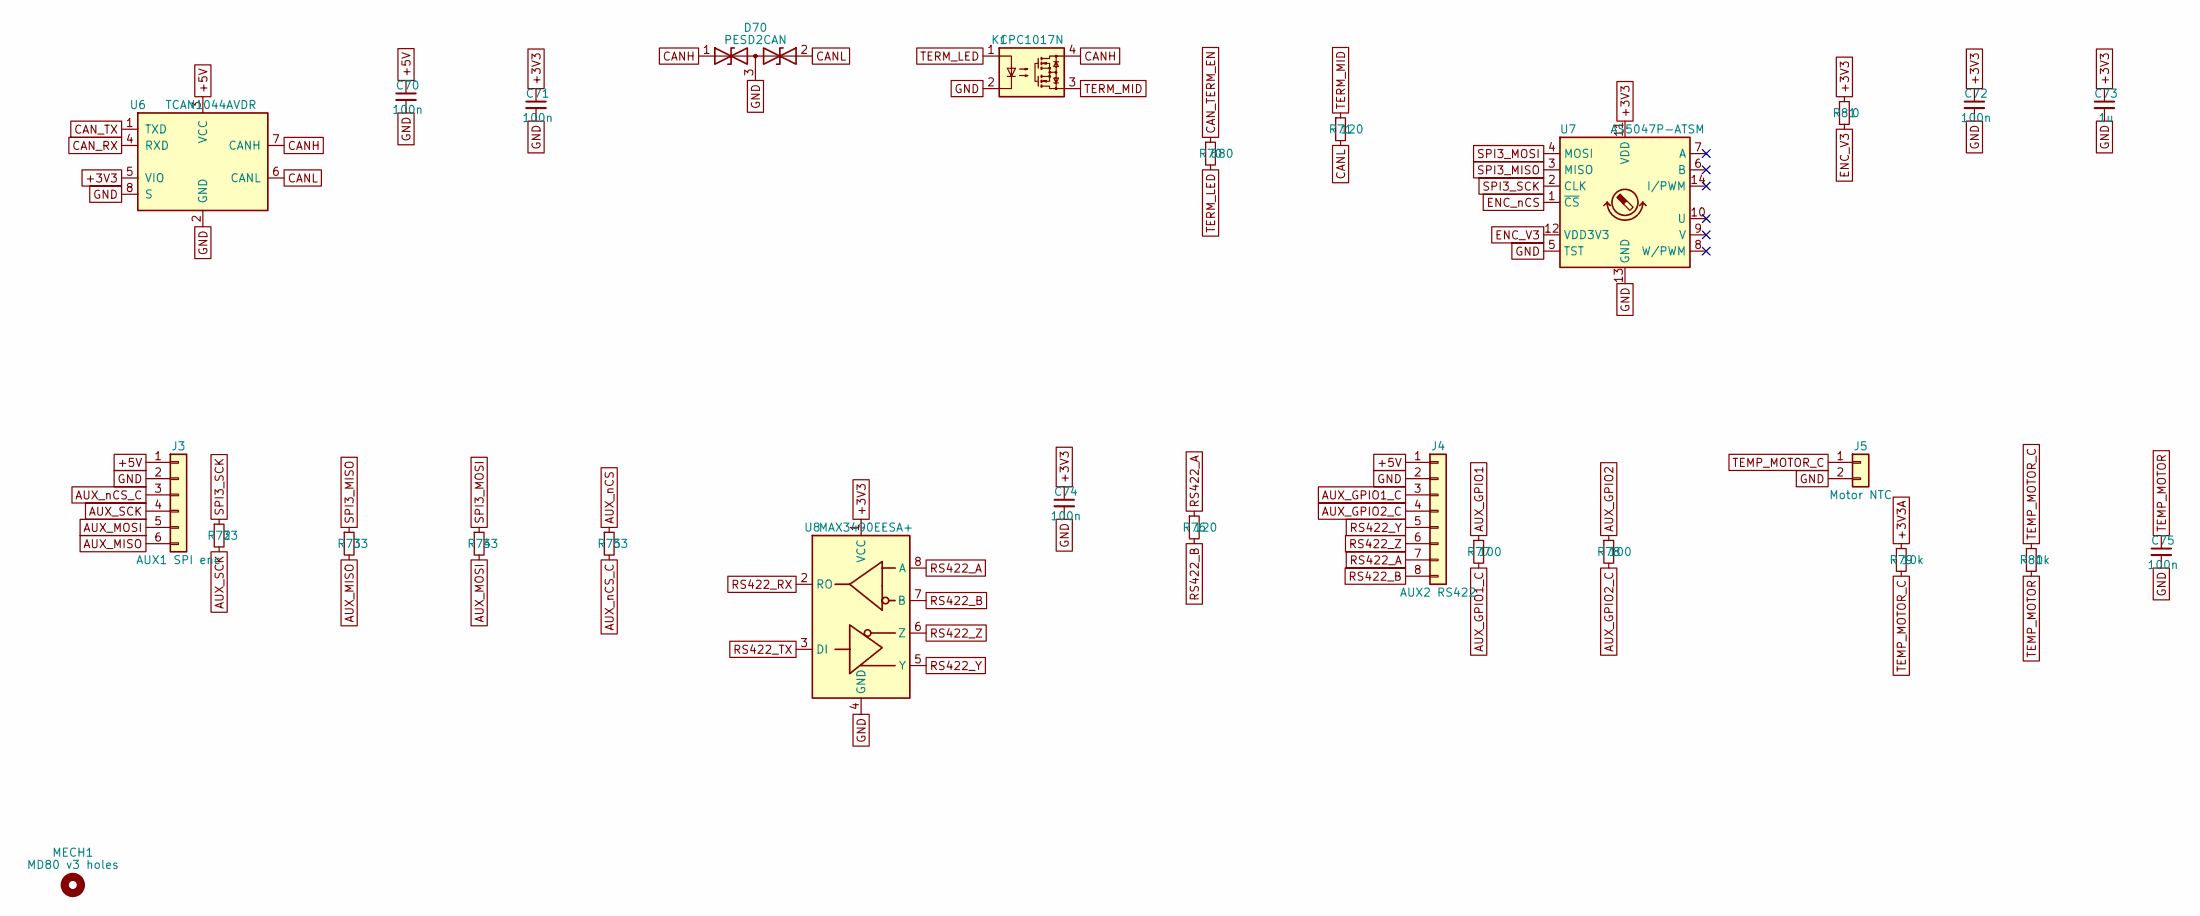
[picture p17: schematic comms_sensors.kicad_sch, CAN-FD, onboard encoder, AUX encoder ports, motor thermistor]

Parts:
C70, C71, C72, C74, C75: 100n; C_0402_1005Metric
C73: 1u; C_0402_1005Metric
D70: PESD2CAN; SOT-23; MPN Nexperia PESD2CAN,215
J3: AUX1 SPI enc; Molex_PicoBlade_53048-0610_1x06_P1.25mm_Horizontal; MPN Molex 53048-0650
J4: AUX2 RS422; Molex_PicoBlade_53048-0810_1x08_P1.25mm_Horizontal; MPN Molex 53048-0850
J5: Motor NTC; MD80_NTC_Pads
K1: CPC1017N; SOP-4_3.8x4.1mm_P2.54mm; MPN IXYS CPC1017NTR
MECH1: MD80 v3 holes; MD80_V3_Mechanical
R70: 680; R_0402_1005Metric
R71, R76: 120; R_0603_1608Metric
R72, R73, R74, R75: 33; R_0402_1005Metric
R77, R78: 100; R_0402_1005Metric
R79: 10k; R_0402_1005Metric
R80: 1k; R_0402_1005Metric
R81: 0; R_0402_1005Metric
U6: TCAN1044AVDR; SOIC-8_3.9x4.9mm_P1.27mm; MPN TI TCAN1044AVDR
U7: AS5047P-ATSM; TSSOP-14_4.4x5mm_P0.65mm; MPN ams OSRAM AS5047P-ATSM
U8: MAX3490EESA+; SOIC-8_3.9x4.9mm_P1.27mm; MPN Analog MAX3490EESA+

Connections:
+3V3: C71.1, C72.1, C73.1, C74.1, R81.1, U6.5 (VIO), U7.11 (VDD), U8.1 (VCC); also elsewhere on the board
+3V3A: R79.1; also elsewhere on the board
+5V: C70.1, J3.1, J4.1, U6.3 (VCC); also elsewhere on the board
AUX_GPIO1: R77.1; also elsewhere on the board
AUX_GPIO1_C: J4.3, R77.2
AUX_GPIO2: R78.1; also elsewhere on the board
AUX_GPIO2_C: J4.4, R78.2
AUX_MISO: J3.6, R73.2
AUX_MOSI: J3.5, R74.2
AUX_SCK: J3.4, R72.2
AUX_nCS: R75.1; also elsewhere on the board
AUX_nCS_C: J3.3, R75.2
CANH: D70.1 (A1), K1.4, U6.7 (CANH); also elsewhere on the board
CANL: D70.2 (A2), R71.2, U6.6 (CANL); also elsewhere on the board
CAN_RX: U6.4 (RXD); also elsewhere on the board
CAN_TERM_EN: R70.1; also elsewhere on the board
CAN_TX: U6.1 (TXD); also elsewhere on the board
ENC_V3: R81.2, U7.12 (VDD3V3)
ENC_nCS: U7.1 (~CS); also elsewhere on the board
GND: C70.2, C71.2, C72.2, C73.2, C74.2, C75.2, D70.3 (common), J3.2, J4.2, J5.2, K1.2, U6.2 (GND), U6.8 (S), U7.5 (TST), U7.13 (GND), U8.4 (GND); also elsewhere on the board
RS422_A: J4.7, R76.1, U8.8 (A)
RS422_B: J4.8, R76.2, U8.7 (B)
RS422_RX: U8.2 (RO); also elsewhere on the board
RS422_TX: U8.3 (DI); also elsewhere on the board
RS422_Y: J4.5, U8.5 (Y)
RS422_Z: J4.6, U8.6 (Z)
SPI3_MISO: R73.1, U7.3 (MISO); also elsewhere on the board
SPI3_MOSI: R74.1, U7.4 (MOSI); also elsewhere on the board
SPI3_SCK: R72.1, U7.2 (CLK); also elsewhere on the board
TEMP_MOTOR: C75.1, R80.2; also elsewhere on the board
TEMP_MOTOR_C: J5.1, R79.2, R80.1
TERM_LED: K1.1, R70.2
TERM_MID: K1.3, R71.1

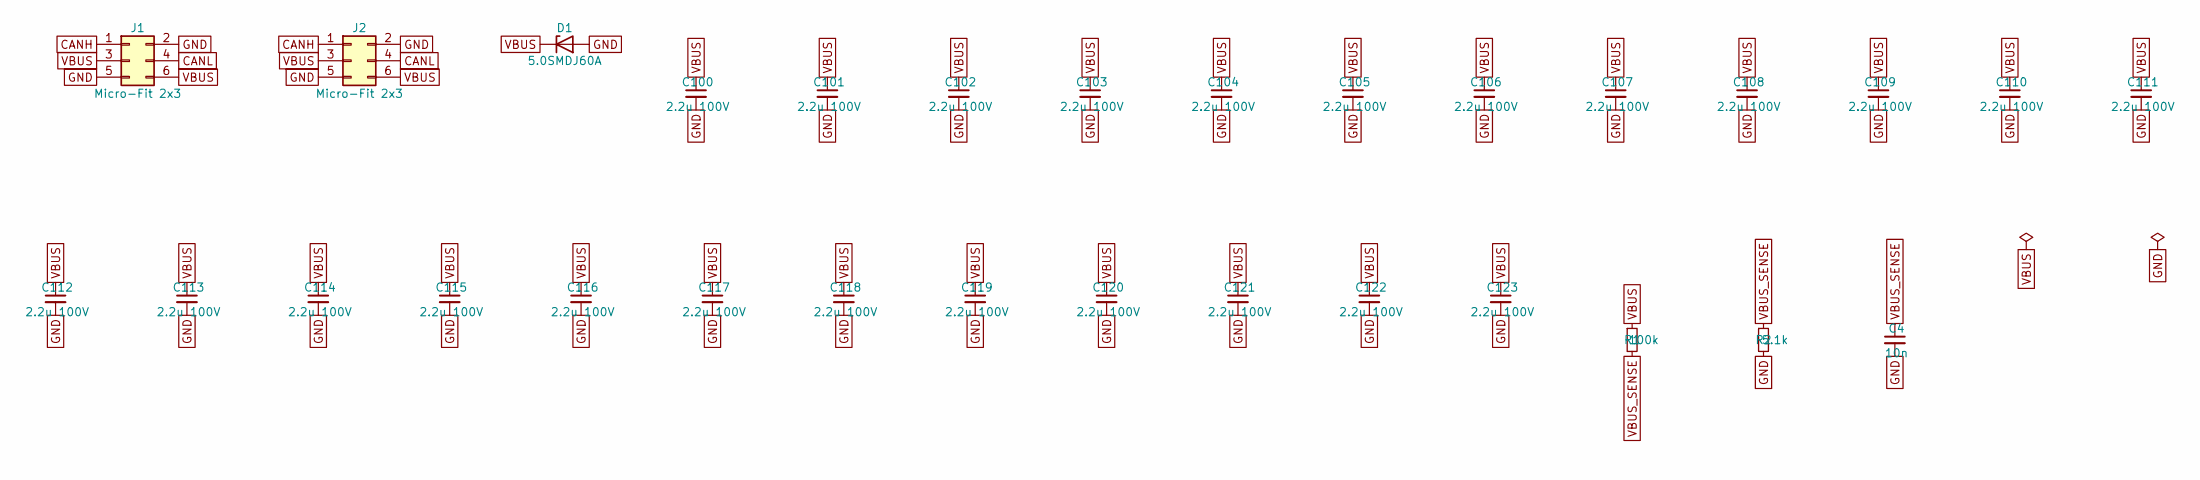
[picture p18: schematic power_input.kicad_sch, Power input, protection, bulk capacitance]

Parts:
C4: 10n; C_0402_1005Metric
C100, C101, C102, C103, C104, C105, C106, C107, C108, C109, C110, C111, C112, C113, C114, C115, C116, C117, C118, C119, C120, C121, C122, C123: 2.2u 100V; C_1206_3216Metric; MPN TDK C3216X7S2A225K160AB
D1: 5.0SMDJ60A; D_SMC; MPN Littelfuse 5.0SMDJ60A
J1, J2: Micro-Fit 2x3; MD80_MicroFit_2x03_RA; MPN Molex 43045-0600 (R/A, 2x3)
R1: 100k; R_0603_1608Metric
R2: 5.1k; R_0402_1005Metric

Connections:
CANH: J1.1, J2.1; also elsewhere on the board
CANL: J1.4, J2.4; also elsewhere on the board
GND: C4.2, C100.2, C101.2, C102.2, C103.2, C104.2, C105.2, C106.2, C107.2, C108.2, C109.2, C110.2, C111.2, C112.2, C113.2, C114.2, C115.2, C116.2, C117.2, C118.2, C119.2, C120.2, C121.2, C122.2, C123.2, D1.2 (A), J1.2, J1.5, J2.2, J2.5, R2.2; also elsewhere on the board
VBUS: C100.1, C101.1, C102.1, C103.1, C104.1, C105.1, C106.1, C107.1, C108.1, C109.1, C110.1, C111.1, C112.1, C113.1, C114.1, C115.1, C116.1, C117.1, C118.1, C119.1, C120.1, C121.1, C122.1, C123.1, D1.1 (K), J1.3, J1.6, J2.3, J2.6, R1.1; also elsewhere on the board
VBUS_SENSE: C4.1, R1.2, R2.1; also elsewhere on the board

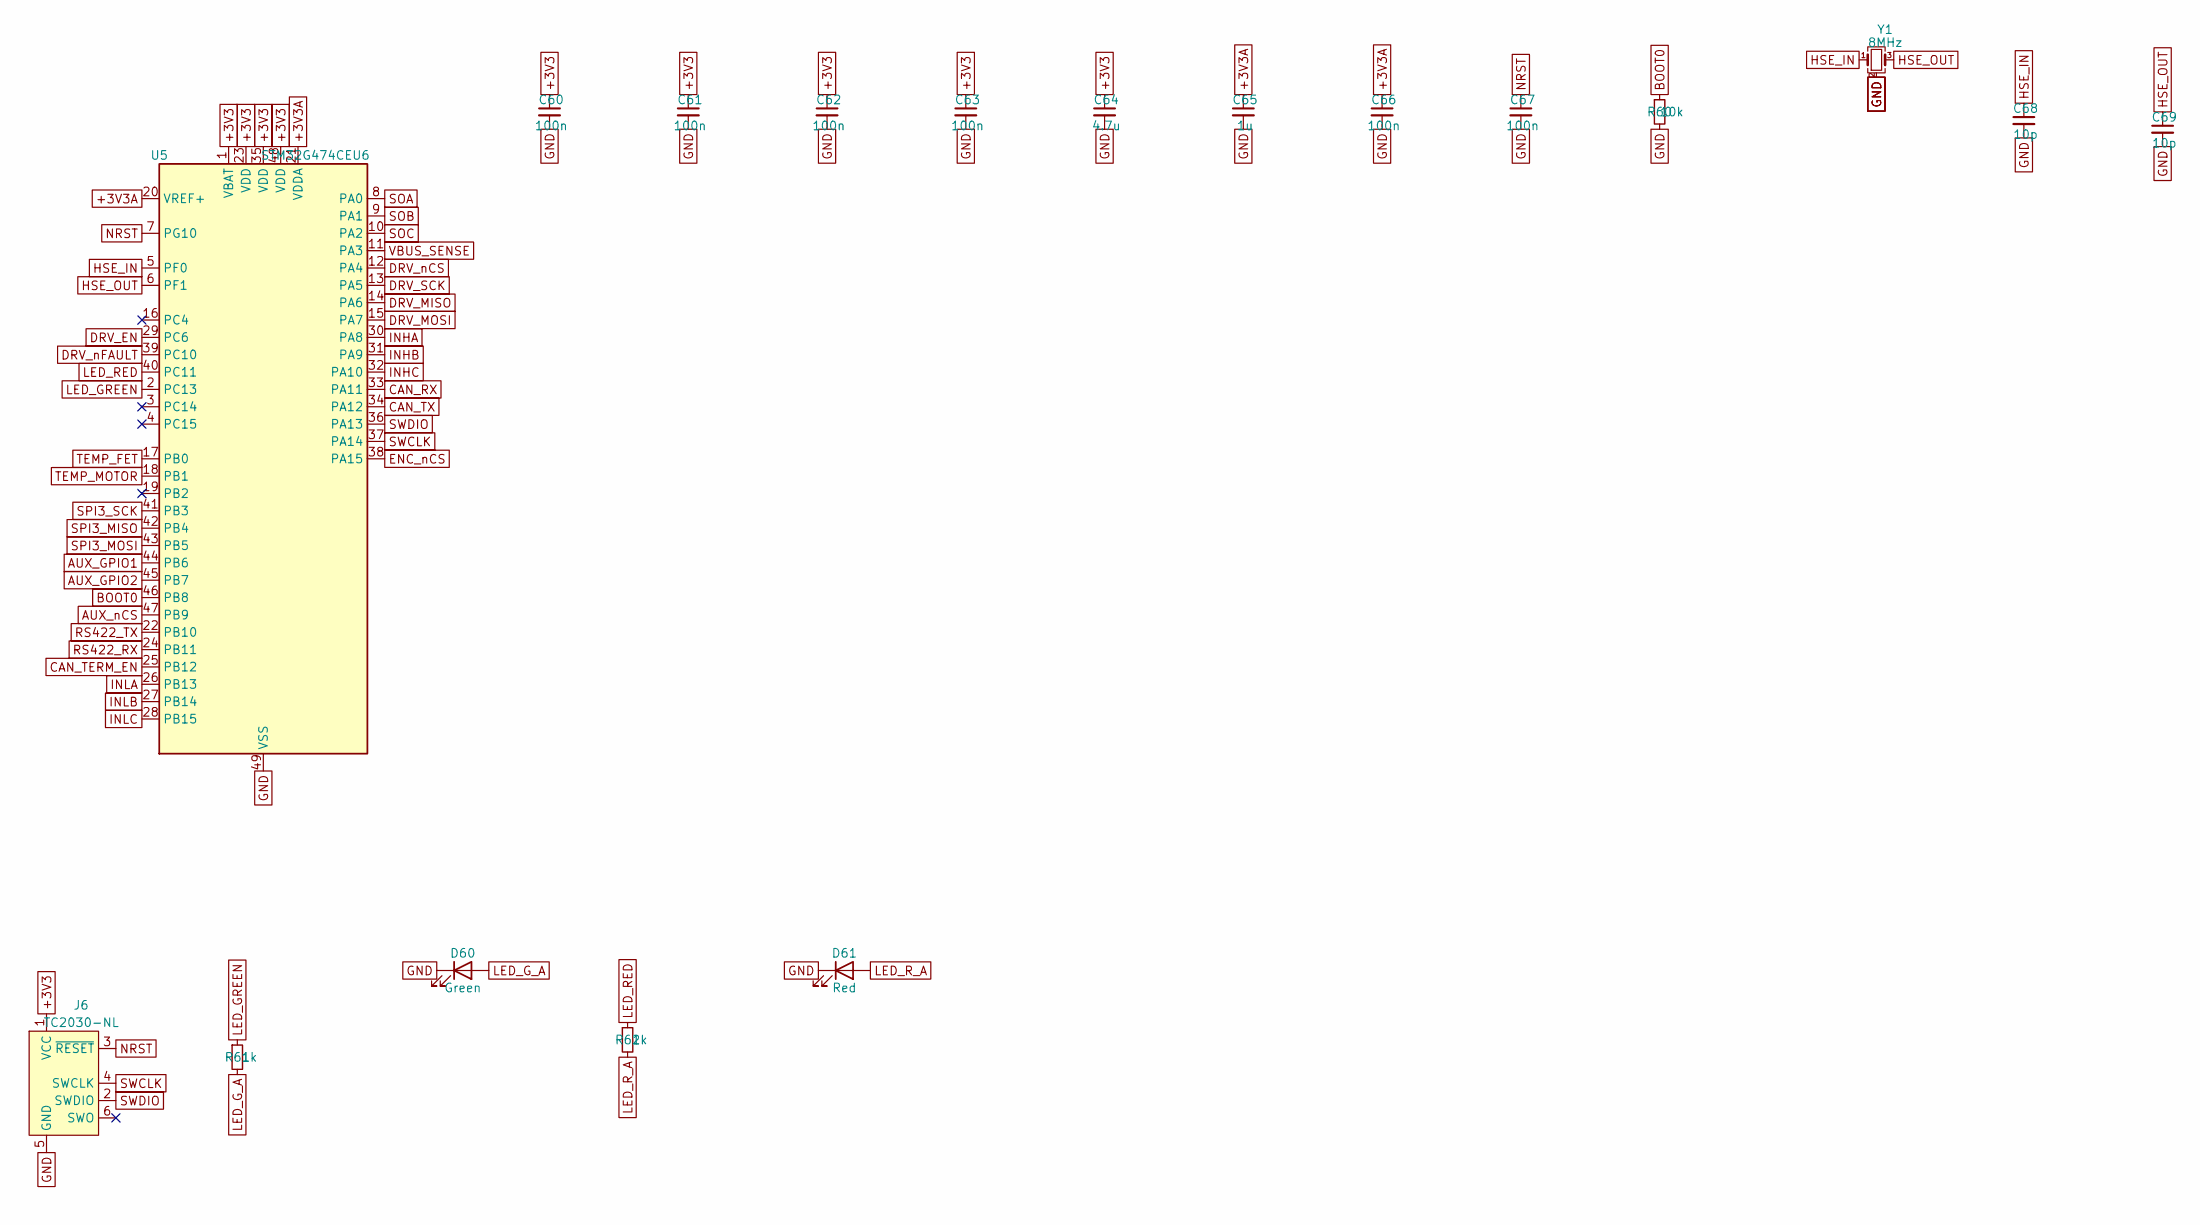
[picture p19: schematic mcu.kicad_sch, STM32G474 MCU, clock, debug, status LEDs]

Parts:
C60, C61, C62, C63, C66, C67: 100n; C_0402_1005Metric
C64: 4.7u; C_0603_1608Metric
C65: 1u; C_0402_1005Metric
C68, C69: 10p; C_0402_1005Metric
D60: Green; LED_0603_1608Metric; MPN Kingbright APTD1608LZGCK
D61: Red; LED_0603_1608Metric; MPN Kingbright APTD1608LSURCK
J6: TC2030-NL; Tag-Connect_TC2030-IDC-NL_2x03_P1.27mm_Vertical
R60: 10k; R_0402_1005Metric
R61, R62: 1k; R_0402_1005Metric
U5: STM32G474CEU6; QFN-48-1EP_7x7mm_P0.5mm_EP5.6x5.6mm; MPN ST STM32G474CEU6
Y1: 8MHz; Crystal_SMD_3225-4Pin_3.2x2.5mm; MPN Abracon ABM8-8.000MHZ-B2-T (verify CL)

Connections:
+3V3: C60.1, C61.1, C62.1, C63.1, C64.1, J6.1 (VCC), U5.1 (VBAT), U5.23 (VDD), U5.35 (VDD), U5.48 (VDD); also elsewhere on the board
+3V3A: C65.1, C66.1, U5.20 (VREF+), U5.21 (VDDA); also elsewhere on the board
AUX_GPIO1: U5.44 (PB6); also elsewhere on the board
AUX_GPIO2: U5.45 (PB7); also elsewhere on the board
AUX_nCS: U5.47 (PB9); also elsewhere on the board
BOOT0: R60.1, U5.46 (PB8)
CAN_RX: U5.33 (PA11); also elsewhere on the board
CAN_TERM_EN: U5.25 (PB12); also elsewhere on the board
CAN_TX: U5.34 (PA12); also elsewhere on the board
DRV_EN: U5.29 (PC6); also elsewhere on the board
DRV_MISO: U5.14 (PA6); also elsewhere on the board
DRV_MOSI: U5.15 (PA7); also elsewhere on the board
DRV_SCK: U5.13 (PA5); also elsewhere on the board
DRV_nCS: U5.12 (PA4); also elsewhere on the board
DRV_nFAULT: U5.39 (PC10); also elsewhere on the board
ENC_nCS: U5.38 (PA15); also elsewhere on the board
GND: C60.2, C61.2, C62.2, C63.2, C64.2, C65.2, C66.2, C67.2, C68.2, C69.2, D60.1 (K), D61.1 (K), J6.5 (GND), R60.2, U5.49 (VSS), Y1.2 (G), Y1.4 (G); also elsewhere on the board
HSE_IN: C68.1, U5.5 (PF0), Y1.1
HSE_OUT: C69.1, U5.6 (PF1), Y1.3
INHA: U5.30 (PA8); also elsewhere on the board
INHB: U5.31 (PA9); also elsewhere on the board
INHC: U5.32 (PA10); also elsewhere on the board
INLA: U5.26 (PB13); also elsewhere on the board
INLB: U5.27 (PB14); also elsewhere on the board
INLC: U5.28 (PB15); also elsewhere on the board
LED_GREEN: R61.1, U5.2 (PC13)
LED_G_A: D60.2 (A), R61.2
LED_RED: R62.1, U5.40 (PC11)
LED_R_A: D61.2 (A), R62.2
NRST: C67.1, J6.3 (~RESET), U5.7 (PG10)
RS422_RX: U5.24 (PB11); also elsewhere on the board
RS422_TX: U5.22 (PB10); also elsewhere on the board
SOA: U5.8 (PA0); also elsewhere on the board
SOB: U5.9 (PA1); also elsewhere on the board
SOC: U5.10 (PA2); also elsewhere on the board
SPI3_MISO: U5.42 (PB4); also elsewhere on the board
SPI3_MOSI: U5.43 (PB5); also elsewhere on the board
SPI3_SCK: U5.41 (PB3); also elsewhere on the board
SWCLK: J6.4 (SWCLK), U5.37 (PA14)
SWDIO: J6.2 (SWDIO), U5.36 (PA13)
TEMP_FET: U5.17 (PB0); also elsewhere on the board
TEMP_MOTOR: U5.18 (PB1); also elsewhere on the board
VBUS_SENSE: U5.11 (PA3); also elsewhere on the board

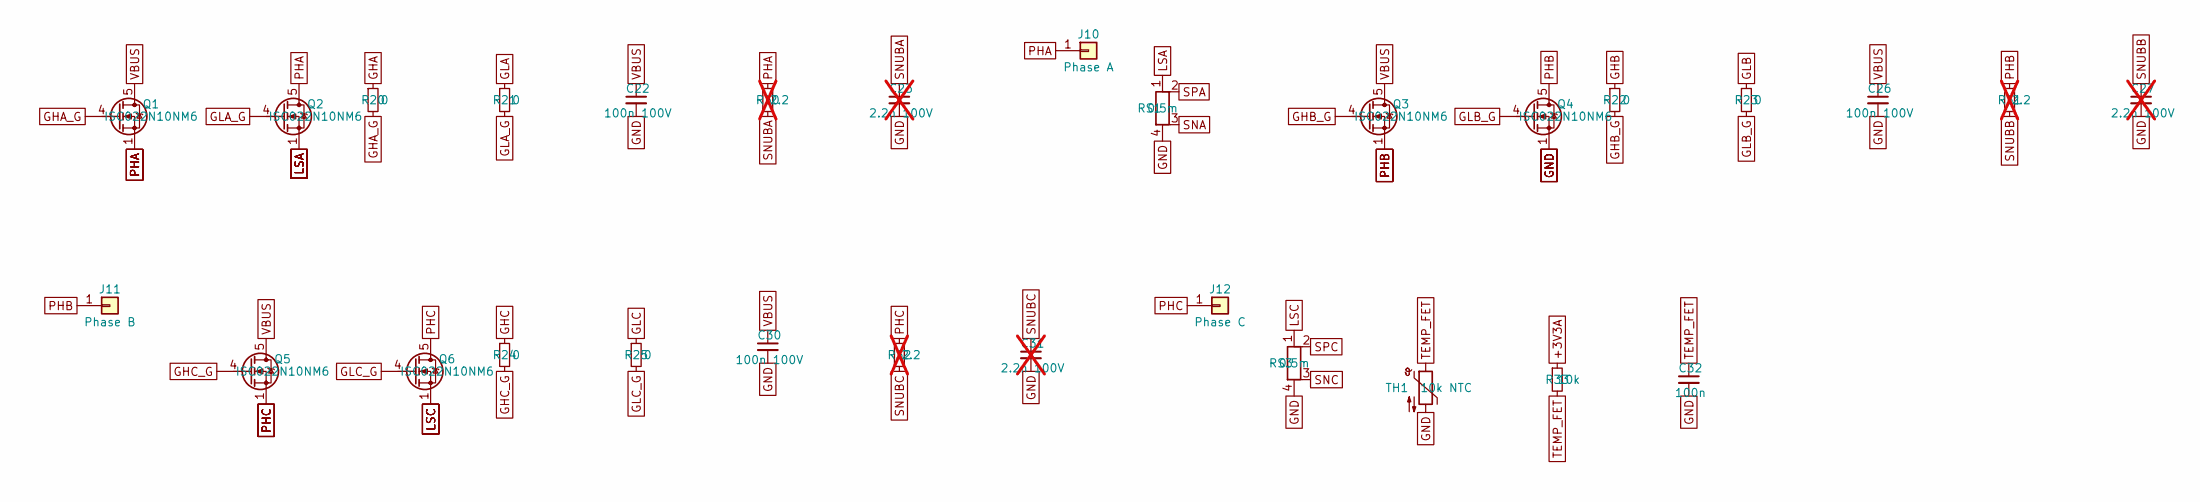
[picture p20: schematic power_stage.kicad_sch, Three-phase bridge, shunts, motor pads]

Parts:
C22, C26, C30: 100n 100V; C_0603_1608Metric; MPN Murata GRM188R72A104KA35D
C23, C27, C31: 2.2n 100V; C_0603_1608Metric; not fitted
C32: 100n; C_0402_1005Metric
J10: Phase A; MD80_Phase_Pad
J11: Phase B; MD80_Phase_Pad
J12: Phase C; MD80_Phase_Pad
Q1, Q2, Q3, Q4, Q5, Q6: ISC022N10NM6; TDSON-8-1; MPN Infineon ISC022N10NM6ATMA1
R20, R21, R22, R23, R24, R25: 0; R_0402_1005Metric
R30, R31, R32: 2.2; R_1206_3216Metric; not fitted
R33: 10k; R_0402_1005Metric
RS1, RS3: 0.5m; R_Shunt_Vishay_WSK2512_6332Metric_T2.66mm; MPN Vishay WSK2512 0.5 mOhm 1% (verify)
TH1: 10k NTC; R_0603_1608Metric; MPN Murata NCP18XH103F03RB

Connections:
+3V3A: R33.1; also elsewhere on the board
GHA: R20.1; also elsewhere on the board
GHA_G: Q1.4 (G), R20.2
GHB: R22.1; also elsewhere on the board
GHB_G: Q3.4 (G), R22.2
GHC: R24.1; also elsewhere on the board
GHC_G: Q5.4 (G), R24.2
GLA: R21.1; also elsewhere on the board
GLA_G: Q2.4 (G), R21.2
GLB: R23.1; also elsewhere on the board
GLB_G: Q4.4 (G), R23.2
GLC: R25.1; also elsewhere on the board
GLC_G: Q6.4 (G), R25.2
GND: C22.2, C23.2, C26.2, C27.2, C30.2, C31.2, C32.2, Q4.1 (S), Q4.2 (S), Q4.3 (S), RS1.4, RS3.4, TH1.2; also elsewhere on the board
LSA: Q2.1 (S), Q2.2 (S), Q2.3 (S), RS1.1
LSC: Q6.1 (S), Q6.2 (S), Q6.3 (S), RS3.1
PHA: J10.1, Q1.1 (S), Q1.2 (S), Q1.3 (S), Q2.5 (D), R30.1; also elsewhere on the board
PHB: J11.1, Q3.1 (S), Q3.2 (S), Q3.3 (S), Q4.5 (D), R31.1; also elsewhere on the board
PHC: J12.1, Q5.1 (S), Q5.2 (S), Q5.3 (S), Q6.5 (D), R32.1; also elsewhere on the board
SNA: RS1.3; also elsewhere on the board
SNC: RS3.3; also elsewhere on the board
SNUBA: C23.1, R30.2
SNUBB: C27.1, R31.2
SNUBC: C31.1, R32.2
SPA: RS1.2; also elsewhere on the board
SPC: RS3.2; also elsewhere on the board
TEMP_FET: C32.1, R33.2, TH1.1; also elsewhere on the board
VBUS: C22.1, C26.1, C30.1, Q1.5 (D), Q3.5 (D), Q5.5 (D); also elsewhere on the board

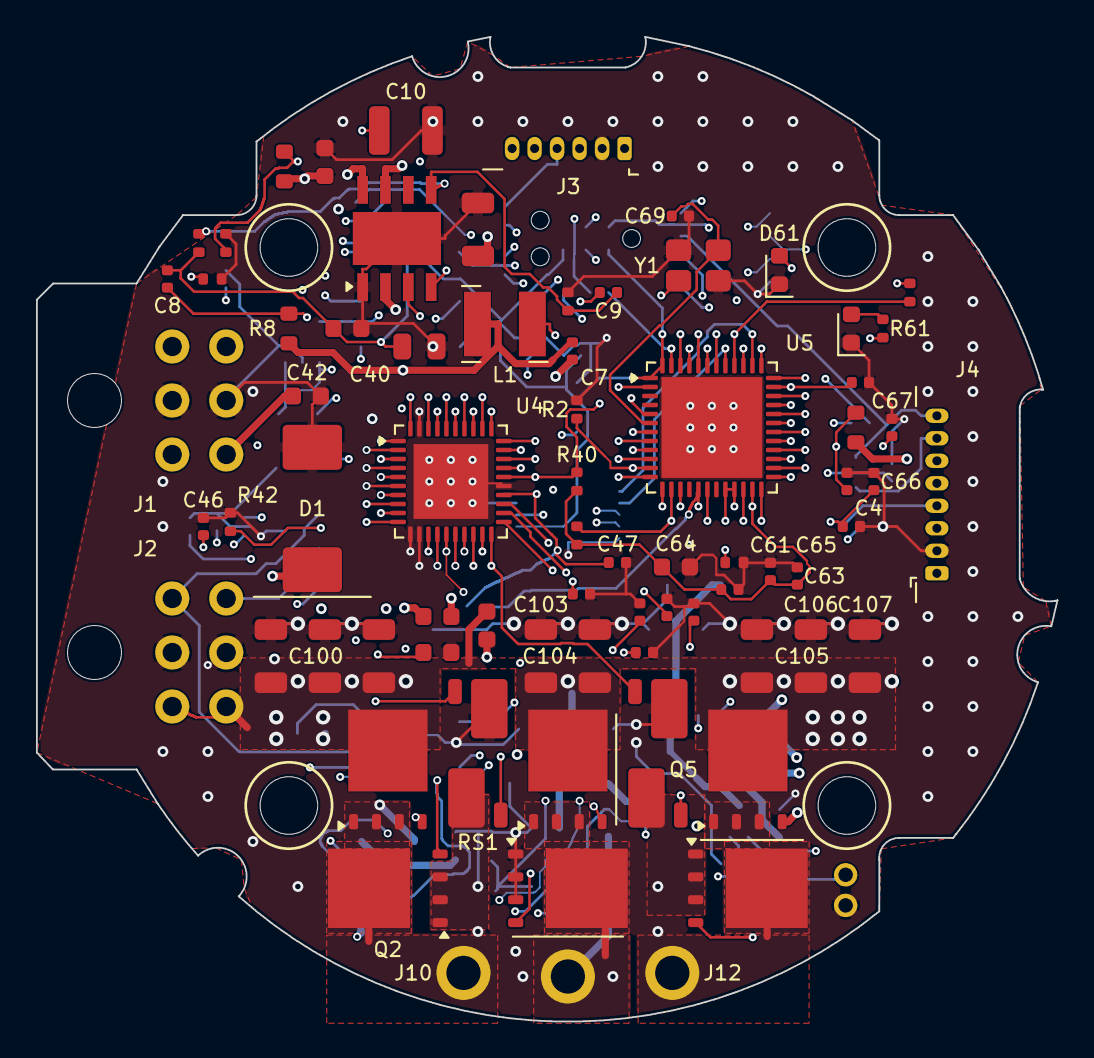
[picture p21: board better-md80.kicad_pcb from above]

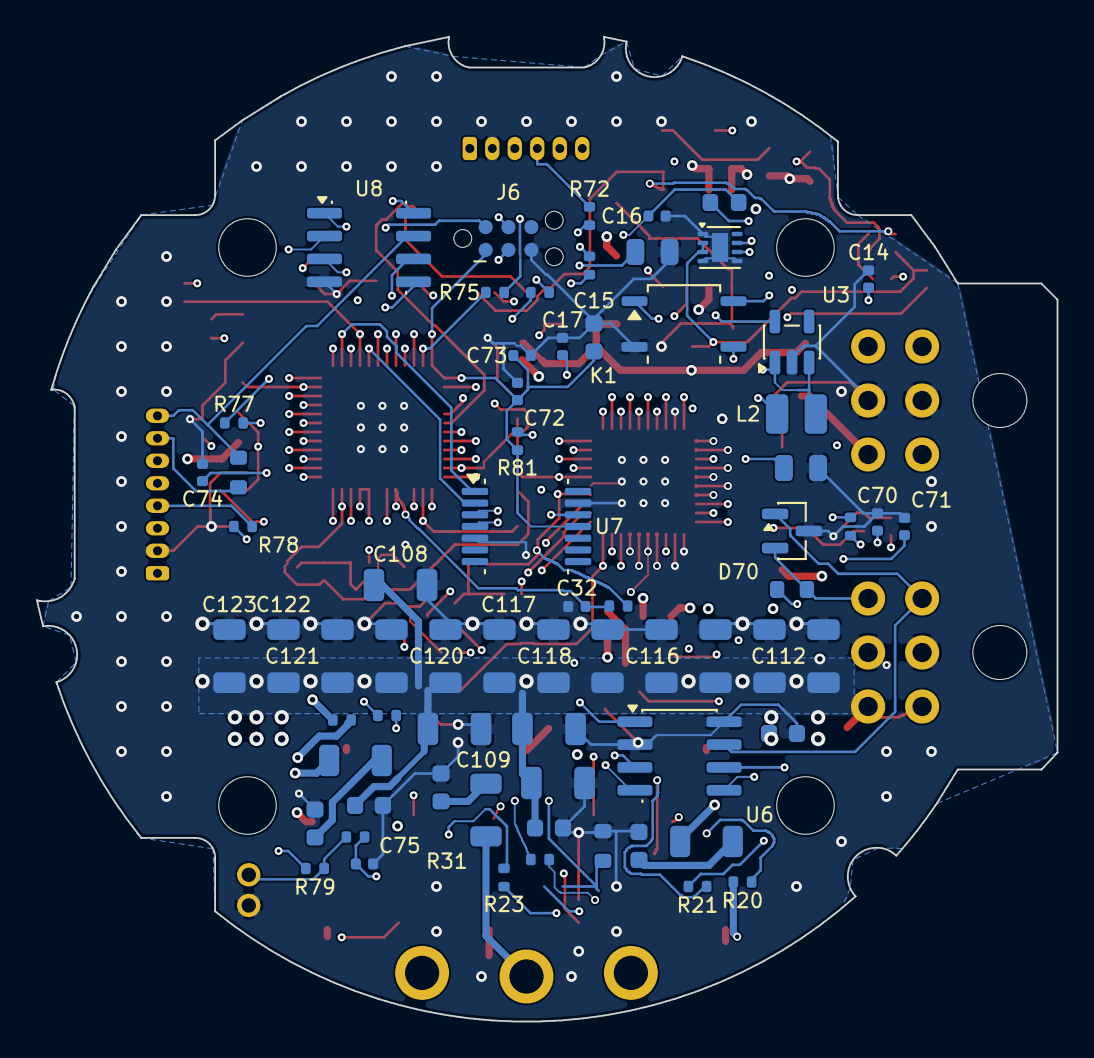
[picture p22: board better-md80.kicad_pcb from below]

Board: 6 copper layers, 56.7 x 54.7 mm, 144 parts (68 on the bottom side), 98 nets.

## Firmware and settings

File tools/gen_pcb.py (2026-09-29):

"""Build hardware/better-md80.kicad_pcb from the schematic netlist.

Run with KiCad's bundled Python:
  "C:/Program Files/KiCad/9.0/bin/python.exe" tools/gen_pcb.py

What it does
  * Edge.Cuts copied from MAB's MD80 v3.0 STEP outline (mech/md80_v3_mech.json)
  * 4-layer stack-up, net classes for the 60 V power nets
  * Mechanically fixed parts (connectors, phase pads, thermistor pads, encoder,
    mounting holes, MOSFETs, shunts, DC-link capacitor rows) at MD80 coordinates
  * Everything else packed into functional zones without courtyard overlap
It does not route. Placement of the packed parts is a starting point for layout.
"""
import json
import math
import os
import sys

import pcbnew

HERE = os.path.dirname(os.path.abspath(__file__))
sys.path.insert(0, HERE)
from sexp import parse, find, find1  # noqa: E402

HW = os.path.normpath(os.path.join(HERE, "..", "hardware"))
STOCK = "C:/Users/darsh/AppData/Local/Programs/KiCad/10.0/share/kicad/footprints/"
MECH = json.load(open(os.path.join(HERE, "..", "mech", "md80_v3_mech.json")))
OX, OY = 150.0, 100.0  # board origin (rotor axis) in KiCad page coordinates


def kc(x, y):
    """STEP (y-up, mm) -> KiCad internal units."""
    return pcbnew.VECTOR2I(pcbnew.FromMM(OX + x), pcbnew.FromMM(OY - y))


# ------------------------------------------------------------------ outline
def outline_points(step=0.5):
    pts = []
    for e in MECH["wires"][0]:
        if e["kind"] == "arc":
            cx, cy = e["center"]
            a0 = math.atan2(e["start"][1] - cy, e["start"][0] - cx)
            a1 = math.atan2(e["end"][1] - cy, e["end"][0] - cx)
            am = math.atan2(e["mid"][1] - cy, e["mid"][0] - cx)
            # choose sweep direction that passes through mid
            def norm(a):
                return a % (2 * math.pi)
            ccw = norm(am - a0) < norm(a1 - a0)
            sweep = norm(a1 - a0) if ccw else -norm(a0 - a1)
            n = max(2, int(abs(sweep) * e["r"] / step))
            pts += [(cx + e["r"] * math.cos(a0 + sweep * k / n), cy + e["r"] * math.sin(a0 + sweep * k / n))
                    for k in range(n)]
        else:
            pts.append(tuple(e["start"]))
    return pts


POLY = outline_points()
_GRID = {}


def ok_point(x, y):
    """Inside the outline with 0.3 mm margin, cached on a 0.05 mm grid."""
    key = (round(x * 20), round(y * 20))
    v = _GRID.get(key)
    if v is None:
        v = inside(x, y) and edge_dist(x, y) >= 0.3
        _GRID[key] = v
    return v


def inside(x, y):
    c = False
    n = len(POLY)
    for i in range(n):
        x1, y1 = POLY[i]
        x2, y2 = POLY[(i + 1) % n]
        if (y1 > y) != (y2 > y) and x < (x2 - x1) * (y - y1) / (y2 - y1) + x1:
            c = not c
    return c


def edge_dist(x, y):
    best = 1e9
    n = len(POLY)
    for i in range(n):
        x1, y1 = POLY[i]
        x2, y2 = POLY[(i + 1) % n]
        dx, dy = x2 - x1, y2 - y1
        t = max(0, min(1, ((x - x1) * dx + (y - y1) * dy) / (dx * dx + dy * dy or 1)))
        best = min(best, math.hypot(x - x1 - t * dx, y - y1 - t * dy))
    return best


def add_outline(board):
    for e in MECH["wires"][0]:
        s = pcbnew.PCB_SHAPE(board)
        s.SetLayer(pcbnew.Edge_Cuts)
        s.SetWidth(pcbnew.FromMM(0.1))
        if e["kind"] == "arc":
            s.SetShape(pcbnew.SHAPE_T_ARC)
            s.SetArcGeometry(kc(*e["start"]), kc(*e["mid"]), kc(*e["end"]))
        else:
            if math.dist(e["start"], e["end"]) < 1e-3:
                continue
            s.SetShape(pcbnew.SHAPE_T_SEGMENT)
            s.SetStart(kc(*e["start"]))
            s.SetEnd(kc(*e["end"]))
        board.Add(s)


# ------------------------------------------------------------------ netlist
def read_netlist():
    t = parse(open(os.path.join(HW, "better-md80.net"), encoding="utf8").read())
    comps = []
    for c in find(find1(t, "components"), "comp"):
        sp = find1(c, "sheetpath")
        props = {find1(p, "name")[1]: (find1(p, "value") or [None, ""])[1] for p in find(c, "property")}
        comps.append(dict(ref=find1(c, "ref")[1], value=find1(c, "value")[1], fp=find1(c, "footprint")[1],
                          path=find1(sp, "tstamps")[1] + find1(c, "tstamps")[1],
                          sheet=props.get("Sheetname", ""), sheetfile=props.get("Sheetfile", ""),
                          dnp="dnp" in props))
    pinnet = {}
    for n in find(find1(t, "nets"), "net"):
        name = find1(n, "name")[1]
        for node in find(n, "node"):
            pinnet[(find1(node, "ref")[1], find1(node, "pin")[1])] = name
    return comps, pinnet


def load_fp(fpid):
    lib, name = fpid.split(":")
    d = os.path.join(HW, "lib", "better_md80.pretty") if lib == "better_md80" else STOCK + lib + ".pretty"
    fp = pcbnew.FootprintLoad(d, name)
    if fp is None:
        raise SystemExit("footprint not found: " + fpid)
    fp.SetFPID(pcbnew.LIB_ID(lib, name))
    return fp


# ------------------------------------------------------------------ placement plan (STEP coords)
PH_X = {"A": -10.0, "B": 0.0, "C": 10.0}
SHUNT_GAP_X = {"A": -5.0, "C": 5.0}   # top-side shunts stand in the gaps between the high-side FETs
SHUNT_Y = -12.6
CAP_X = [-16.5 + 3.0 * k for k in range(12)]
CAP_X_TOP = [x for x in CAP_X if abs(abs(x) - 6.0) > 2.0]  # keep the shunt gaps free

FIXED = {  # ref: (x, y, rotation_deg, side)
    "MECH1": (0, 0, 0, "F"),
    "J1": (-21.98, 7.0, 0, "F"), "J2": (-21.98, -7.0, 0, "F"),
    "J3": (3.15, 21.0, 180, "F"), "J4": (20.5, -2.6, 90, "F"),
    "J5": (15.43, -19.35, 0, "F"),
    "J10": (-5.8, -24.8, 0, "F"), "J11": (0.0, -25.0, 0, "F"), "J12": (5.8, -24.8, 0, "F"),
    "U7": (0, 0, 0, "B"),
    "D1": (-14.2, 1.0, 90, "F"),   # 5.0SMDJ60A, SMC, next to the power entry
}
for i, ph in enumerate("ABC"):
    FIXED["Q%d" % (2 * i + 1)] = (PH_X[ph], -13.5, 90, "F")   # high side, drain towards DC link
    # low side: A's sources face the A/B gap (rot 180), B and C sources face left (rot 0)
    FIXED["Q%d" % (2 * i + 2)] = (PH_X[ph], -20.1, 180 if ph == "A" else 0, "F")
for i, ph in enumerate("ABC"):
    if ph in SHUNT_GAP_X:
        FIXED["RS%d" % (i + 1)] = (SHUNT_GAP_X[ph], SHUNT_Y, 90, "F")   # pad 1 (low-side end) down
top_caps = ["C%d" % (100 + k) for k in range(12)]
for ref, x in zip(top_caps, CAP_X_TOP):
    FIXED[ref] = (x, -7.2, 90, "F")
for k, x in enumerate(CAP_X):
    FIXED["C%d" % (112 + k)] = (x, -7.2, 90, "B")
EXTRA_CAPS = top_caps[len(CAP_X_TOP):]   # the rest of the DC-link caps are packed near the bus

ZONES = [  # (refs, (x, y), side)
    (["U4", "C40", "C41", "C42", "C43", "C44", "C45", "C46", "C47", "R40", "R41", "R42"], (-8.5, 2.5), "F"),
    (["C48", "C49", "C50"], (2.0, -2.5), "F"),
    (["U5", "Y1", "C68", "C69", "C60", "C61", "C62", "C63", "C64", "C65", "C66", "C67", "R60",
      "R1", "R2", "C4"], (8.0, 5.5), "F"),
    (["R61", "R62", "D60", "D61"], (14.5, 13.0), "F"),
    (["J6"], (8.0, 13.0), "B"),
    (["U1", "C5", "C6", "R3", "R4", "R5", "C7", "L1", "R6", "R7", "R8", "C8", "C9", "C10", "C11"], (-10.0, 16.0), "F"),
    (["U2", "C12", "L2", "C13", "U3", "C14", "C15", "FB1", "C16", "C17"], (-12.0, 9.0), "B"),
    (["U6", "C70", "C71", "D70", "K1", "R70", "R71"], (-13.0, -1.0), "B"),
    (["C72", "C73", "R81"], (0.0, 4.0), "B"),
    (["R72", "R73", "R74", "R75"], (0.0, 16.5), "B"),
    (["U8", "C74", "R76", "R77", "R78"], (14.0, 3.0), "B"),
    (["R79", "R80", "C75"], (12.0, -17.0), "B"),
    (["TH1", "R33", "C32"], (-2.0, -16.5), "B"),
    (EXTRA_CAPS, (0.0, -3.8), "B"),
    (["R20", "R21", "C22", "R30", "C23"], (-10.0, -13.0), "B"),
    (["R22", "R23", "C26", "R31", "C27"], (0.0, -13.0), "B"),
    (["R24", "R25", "C30", "R32", "C31"], (9.5, -13.0), "B"),
]


FANOUT_RING = {"U4": 2.2, "U5": 2.2}


class Packer:
    def __init__(self):
        self.occ = {"F": [], "B": []}

    @staticmethod
    def rel_bbox(fp, rot, side):
        fp.SetPosition(pcbnew.VECTOR2I(0, 0))
        fp.SetOrientationDegrees(rot)
        cy = fp.GetCourtyard(pcbnew.F_CrtYd)
        bb = cy.BBox() if cy.OutlineCount() else fp.GetBoundingBox(False)
        x1, y1 = pcbnew.ToMM(bb.GetLeft()), -pcbnew.ToMM(bb.GetBottom())
        x2, y2 = pcbnew.ToMM(bb.GetRight()), -pcbnew.ToMM(bb.GetTop())
        if side == "B":
            x1, x2 = -x2, -x1
        return x1, y1, x2, y2

    def fits(self, box, side, margin=0.4):
        x1, y1, x2, y2 = box
        for (a1, b1, a2, b2) in self.occ[side]:
            if x1 < a2 + margin and x2 > a1 - margin and y1 < b2 + margin and y2 > b1 - margin:
                return False
        for (px, py) in ((x1, y1), (x1, y2), (x2, y1), (x2, y2), ((x1 + x2) / 2, y1), ((x1 + x2) / 2, y2),
                         (x1, (y1 + y2) / 2), (x2, (y1 + y2) / 2)):
            if not ok_point(px, py):
                return False
        return True

    def occupy(self, box, side):
        self.occ[side].append(box)

    def find(self, fp, center, side, rots=(0, 90)):
        cx, cy = center
        rels = [(r, self.rel_bbox(fp, r, side)) for r in rots]
        for ring in range(0, 70):
            rad = ring * 0.5
            steps = max(1, int(2 * math.pi * rad / 0.5))
            for k in range(steps):
                a = 2 * math.pi * k / steps
                x, y = cx + rad * math.cos(a), cy + rad * math.sin(a)
                x, y = round(x * 4) / 4, round(y * 4) / 4
                for r, (a1, b1, a2, b2) in rels:
                    box = (x + a1, y + b1, x + a2, y + b2)
                    if self.fits(box, side):
                        return x, y, r, box
        return None


def put(fp, x, y, rot, side):
    fp.SetPosition(pcbnew.VECTOR2I(0, 0))
    fp.SetOrientationDegrees(rot)
    if side == "B":
        fp.Flip(pcbnew.VECTOR2I(0, 0), pcbnew.FLIP_DIRECTION_LEFT_RIGHT)
    fp.SetPosition(kc(x, y))


def main():
    comps, pinnet = read_netlist()
    board = pcbnew.CreateEmptyBoard()
    board.SetCopperLayerCount(6)
    ds = board.GetDesignSettings()
    ds.SetBoardThickness(pcbnew.FromMM(1.6))
    ds.m_CopperEdgeClearance = pcbnew.FromMM(0.3)
    add_outline(board)

    nets = {}
    for name in sorted(set(pinnet.values())):
        ni = pcbnew.NETINFO_ITEM(board, name)
        board.Add(ni)
        nets[name] = ni

    fps = {}
    for c in comps:
        if c["ref"].startswith("#"):
            continue
        fp = load_fp(c["fp"])
        fp.SetReference(c["ref"])
        fp.SetValue(c["value"])
        fp.SetPath(pcbnew.KIID_PATH(c["path"]))
        try:
            fp.SetSheetname(c["sheet"])
            fp.SetSheetfile(c["sheetfile"])
        except AttributeError:
            pass
        for pad in fp.Pads():
            net = pinnet.get((c["ref"], pad.GetNumber()))
            if net and not net.startswith("unconnected-"):
                pad.SetNet(nets[net])
        board.Add(fp)
        fps[c["ref"]] = fp

    pk = Packer()
    placed = set()

    def area(r):
        b = pk.rel_bbox(fps[r], 0, "F")
        return (b[2] - b[0]) * (b[3] - b[1])
    order = sorted(fps, key=lambda r: -area(r))  # before placing: rel_bbox moves parts to the origin
    for ref, (x, y, rot, side) in FIXED.items():
        fp = fps[ref]
        rel = pk.rel_bbox(fp, rot, side)
        put(fp, x, y, rot, side)
        box = (x + rel[0], y + rel[1], x + rel[2], y + rel[3])
        placed.add(ref)
        if ref == "MECH1":  # its keep-outs are added individually below
            continue
        pk.occupy(box, side)
        if fp.GetAttributes() & pcbnew.FP_THROUGH_HOLE or ref.startswith(("J", "MECH")):
            pk.occupy(box, "B" if side == "F" else "F")
    # mechanical keep-outs (screw heads / standoffs) on both sides
    for w in MECH["wires"][1:]:
        e = w[0]
        if len(w) == 1 and 1.55 <= e["r"] <= 1.65:
            x, y = e["center"]
            for s in "FB":
                pk.occupy((x - 2.4, y - 2.4, x + 2.4, y + 2.4), s)
    for (x, y) in ((26.56, -7.12), (-7.12, 26.57), (-19.45, -19.45)):
        for s in "FB":
            pk.occupy((x - 2.25, y - 2.25, x + 2.25, y + 2.25), s)

    failed = []
    zone_of = {}
    for refs, center, side in ZONES:
        for r in refs:
            zone_of[r] = (center, side)
    for ref in order:
        if ref in placed:
            continue
        center, side = zone_of.get(ref, ((4.0, -2.0), "F"))
        if ref in ("Y1", "C68", "C69") and "U5" in placed:
            u5 = fps["U5"]
            pins = {p.GetNumber(): p.GetPosition() for p in u5.Pads()}
            c5 = u5.GetPosition()
            hx = (pins["5"].x + pins["6"].x) / 2
            hy = (pins["5"].y + pins["6"].y) / 2
            dx, dy = hx - c5.x, hy - c5.y
            L = max(1, math.hypot(dx, dy))
            d = pcbnew.FromMM({"Y1": 5.2, "C68": 7.6, "C69": 7.6}[ref])
            px, py = hx + dx / L * d, hy + dy / L * d
            off = {"Y1": 0, "C68": -1.6, "C69": 1.6}[ref]
            px += -dy / L * pcbnew.FromMM(off)
            py += dx / L * pcbnew.FromMM(off)
            center, side = ((pcbnew.ToMM(px) - OX, OY - pcbnew.ToMM(py)), "F")
        res = pk.find(fps[ref], center, side)
        if res is None:
            side = "B" if side == "F" else "F"
            res = pk.find(fps[ref], center, side)
        if res is None:
            failed.append(ref)
            put(fps[ref], 40, 0, 0, "F")
            continue
        x, y, rot, box = res
        put(fps[ref], x, y, rot, side)
        pk.occupy(box, side)
        if any(p.GetDrillSize().x > 0 for p in fps[ref].Pads()):  # holes go through both sides
            pk.occupy(box, "B" if side == "F" else "F")
        if ref in FANOUT_RING:  # keep a via fan-out ring free on both sides
            r = FANOUT_RING[ref]
            ring = (box[0] - r, box[1] - r, box[2] + r, box[3] + r)
            pk.occupy(ring, "F")
            pk.occupy(ring, "B")
        placed.add(ref)

    # net classes: 60 V power nets get wider clearance
    ns = ds.m_NetSettings
    hv = pcbnew.NETCLASS("HV_60V")
    hv.SetClearance(pcbnew.FromMM(0.2))
    hv.SetTrackWidth(pcbnew.FromMM(0.5))
    hv.SetViaDiameter(pcbnew.FromMM(0.8))
    hv.SetViaDrill(pcbnew.FromMM(0.4))
    try:
        ns.SetNetclass("HV_60V", hv)
        for pat in ("VBUS", "PH*", "SW12", "BST12", "GH*", "CPH", "CPL", "VCP", "SNUB*"):
            ns.SetNetclassPatternAssignment(pat, "HV_60V")
    except Exception as ex:  # API differs between 9.0.x releases
        print("net class setup skipped:", ex)

    out = os.path.join(HW, "better-md80.kicad_pcb")
    board.Save(out)
    print("saved", out, "footprints:", len(fps), "unplaced:", failed)


if __name__ == "__main__":
    main()

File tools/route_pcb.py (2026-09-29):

"""Copper pours, power vias, autorouting hand-off and silkscreen clean-up.

Run with KiCad 10's Python, in this order (tools/route.sh does it):
  route_pcb.py pours      add zones + power-stage stitching vias, export hardware/route/board.dsn
  (freerouting)           route board.dsn -> board.ses
  route_pcb.py finish     import board.ses, refill zones, fix silkscreen, save

Coordinates here are MD80 STEP coordinates (mm, y up, origin on the rotor axis).
"""
import math
import os
import sys

import pcbnew

HERE = os.path.dirname(os.path.abspath(__file__))
sys.path.insert(0, HERE)
import gen_pcb  # noqa: E402  (outline polygon, coordinate helper, phase positions)

HW = gen_pcb.HW
PCB = os.environ.get("BMD_PCB", os.path.join(HW, "better-md80.kicad_pcb"))
RDIR = os.environ.get("BMD_RDIR", os.path.join(HW, "route"))
kc = gen_pcb.kc
MM = pcbnew.FromMM


def netcode(board, name):
    return board.FindNet(name)


# ------------------------------------------------------------------ zones
def add_zone(board, net, layer, pts, priority=0, clearance=0.2, min_width=0.2, solid=True, name=""):
    z = pcbnew.ZONE(board)
    z.SetLayer(layer)
    z.SetNet(netcode(board, net))
    z.SetAssignedPriority(priority)
    z.SetLocalClearance(MM(clearance))
    z.SetMinThickness(MM(min_width))
    z.SetPadConnection(pcbnew.ZONE_CONNECTION_FULL if solid else pcbnew.ZONE_CONNECTION_THERMAL)
    z.SetThermalReliefGap(MM(0.25))
    z.SetThermalReliefSpokeWidth(MM(0.35))
    z.SetIslandRemovalMode(pcbnew.ISLAND_REMOVAL_MODE_ALWAYS)
    if name:
        z.SetZoneName(name)
    ol = z.Outline()
    ol.NewOutline()
    for (x, y) in pts:
        ol.Append(kc(x, y))
    board.Add(z)
    return z


def rect(x1, y1, x2, y2):
    return [(x1, y1), (x2, y1), (x2, y2), (x1, y2)]


def board_poly():
    return gen_pcb.POLY[::3]


def add_power_pours(board):
    """Local power-stage copper. Nothing of another net lies inside these, so the
    autorouter can treat them as fixed conduction areas.

    Layout (STEP coordinates): high-side FETs at y = -13.5, low-side FETs at y = -20.1,
    top-side shunts for phases A and C standing in the gaps at x = -5 / +5, phase B's
    low side returns straight to GND (two-shunt sensing)."""
    F, B, I4 = pcbnew.F_Cu, pcbnew.B_Cu, pcbnew.In4_Cu
    add_zone(board, "GND", pcbnew.In1_Cu, board_poly(), 0, name="GND plane")
    # VBUS over the high-side drains, with notches for the two shunt gaps
    vb = [(-18.2, -7.3), (18.2, -7.3), (18.2, -12.4), (7.1, -12.4), (7.1, -7.9), (2.9, -7.9), (2.9, -12.4),
          (-2.9, -12.4), (-2.9, -7.9), (-7.1, -7.9), (-7.1, -12.4), (-18.2, -12.4)]
    add_zone(board, "VBUS", F, vb, 5, name="VBUS top")
    add_zone(board, "VBUS", B, rect(-18.2, -7.3, 18.2, -10.4), 5, name="VBUS bottom")
    for ph, x0 in gen_pcb.PH_X.items():
        hole_x = {"A": -5.8, "B": 0.0, "C": 5.8}[ph]
        s = -1 if ph == "A" else 1          # side of the low-side drain pad
        net = "PH" + ph
        add_zone(board, net, F, rect(x0 - 2.4, -15.3, x0 + 1.2, -17.9), 6, name=net + " top")
        d1, d2 = sorted((x0 + s * (1.05 - 2.35), x0 + s * (1.05 + 2.35)))
        add_zone(board, net, F, rect(d1, -17.5, d2, -22.6), 10)
        add_zone(board, net, F, rect(min(d1, hole_x - 1.9), -22.7, max(d2, hole_x + 1.9), -27.6), 11)
        lo = {"A": (-14.6, -4.6), "B": (-4.2, 4.2), "C": (4.6, 14.2)}[ph]
        add_zone(board, net, I4, rect(lo[0], -15.5, lo[1], -27.6), 6, name=net + " In4")
    # low-side sources -> shunt pad 1 (top side, around the gate pin)
    add_zone(board, "LSA", F, [(-7.6, -22.4), (-4.4, -22.4), (-4.4, -14.9), (-6.4, -14.9), (-6.4, -18.6),
                               (-7.6, -18.6)], 7, name="LSA top")
    add_zone(board, "LSC", F, rect(4.4, -21.6, 7.6, -14.9), 7, name="LSC top")


def add_general_pours(board):
    """Board-wide pours, added after routing so they flow around the tracks."""
    F, B = pcbnew.F_Cu, pcbnew.B_Cu
    full = board_poly()
    add_zone(board, "GND", F, full, 0, solid=False, name="GND top")
    add_zone(board, "GND", B, full, 0, solid=False, name="GND bottom")
    for L, nm in ((pcbnew.In2_Cu, "In2"), (pcbnew.In3_Cu, "In3"), (pcbnew.In4_Cu, "In4")):
        add_zone(board, "GND", L, full, 0, solid=True, name="GND %s fill" % nm)
    # VBUS plane: Micro-Fit strip, the TVS D1, and the power stage
    add_zone(board, "VBUS", pcbnew.In4_Cu, [(-30, 5.6), (-16.6, 5.6), (-16.6, -0.3), (-12.8, -0.3), (-12.8, -3.4),
                                            (19.5, -3.4), (19.5, -15.1),
                                 (-30, -15.1)], 5, name="VBUS plane")


# ------------------------------------------------------------------ vias
def box_dist(bb, p):
    """Distance in mm from point p (VECTOR2I) to box bb; 0 inside."""
    dx = max(bb.GetLeft() - p.x, 0, p.x - bb.GetRight())
    dy = max(bb.GetTop() - p.y, 0, p.y - bb.GetBottom())
    return pcbnew.ToMM(int(math.hypot(dx, dy)))


HV_NETS = {"VBUS", "PHA", "PHB", "PHC", "SW12", "BST12", "GHA", "GHB", "GHC", "GHA_G", "GHB_G", "GHC_G",
           "CPH", "CPL", "VCP"}


def seg_dist(p, a, b):
    ax, ay, bx, by, px, py = a.x, a.y, b.x, b.y, p.x, p.y
    dx, dy = bx - ax, by - ay
    L = dx * dx + dy * dy
    t = 0 if L == 0 else max(0, min(1, ((px - ax) * dx + (py - ay) * dy) / L))
    return pcbnew.ToMM(int(math.hypot(px - ax - t * dx, py - ay - t * dy)))


def fix_vias_tracks(board, min_w=0.1, min_ring=0.1):
    """Make autorouter output meet fab minimums: via annular ring and neck-down widths."""
    rings = necks = 0
    for t in board.GetTracks():
        if t.Type() == pcbnew.PCB_VIA_T:
            size, drill = t.GetWidth(pcbnew.F_Cu), t.GetDrillValue()
            if (size - drill) / 2 < MM(min_ring) - 10:
                t.SetDrill(size - 2 * MM(min_ring))
                rings += 1
        elif t.GetWidth() < MM(min_w) - 10:
            t.SetWidth(MM(min_w))
            necks += 1
    return rings, necks
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

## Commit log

2026-09-28 better-md80: 60 V MD80-compatible controller, schematic, placed PCB, docs
    [better-md80.kicad_pcb, better-md80.kicad_sch, bom.csv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]
2026-09-28 Route the board: KiCad 10, 6 layers, pours, fan-out, silkscreen clean-up
    Autorouted with Freerouting after QFN fan-out; remaining nets routed with
    tools/hand_route.py. DRC: 0 unconnected, only the MD80-inherent AUX1/screw
    courtyard overlap. GND plane on In1 still carries signal tracks (next pass).
    [better-md80.kicad_pcb, better-md80.kicad_sch, comms_sensors.kicad_sch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]
2026-09-28 Re-route with a solid In1 GND plane; add simulations
    Freerouting re-run with In1 locked as a power plane (0 signal tracks on In1),
    leftovers routed with tools/hand_route.py. DRC: 0 unconnected, only the
    MD80-inherent AUX1/screw courtyard overlap.
    sim/: FastHenry loop inductance (5.0 nH), LTspice double pulse and bus
    surge/regen, MATLAB current loop. Findings and recommended changes in
    docs/simulation.md.
    [better-md80.kicad_pcb]
2026-09-28 Solid GND connection for AUX1 shield pad; keep raw simulation data out of git
    [better-md80.kicad_pcb]
2026-09-29 Layout tools: board-outline check in move_part, TVS plane vias, pass-2 prep
    Pass-2 trial (SMC TVS, crystal move) did not improve the board and was not kept;
    see thread notes. Board file unchanged from c99b00a+.
2026-09-29 Layout rev B: top-side two-shunt power stage, 5.0SMDJ60A TVS, crystal by the MCU
    Commutation loop 5.0 -> 3.0 nH (FastHenry), 60 V hot-plug peak 106 -> 96 V.
    Re-placed and re-routed (Freerouting + tools/hand_route.py); DRC: 0 unconnected,
    only the MD80-inherent AUX1/screw courtyard overlap. Docs and sims updated.
    [better-md80.kicad_pcb, bom.csv, gate_driver.kicad_sch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]
2026-10-08 Rename to bldc-controller-60v in the README and architecture doc
